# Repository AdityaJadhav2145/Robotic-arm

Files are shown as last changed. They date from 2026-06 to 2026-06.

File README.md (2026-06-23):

# Robotic-arm
"5-DOF Robotic Arm | Arduino UNO + MG995 Servos | SolidWorks CAD &amp; FEA | 3D Printed (PUR)"

 Key Features
 5-DOF Articulated Design - Maximum workspace flexibility for pick-and-place, welding, and assembly tasks

 Cost-Effective - Built with affordable components and 3D printing technology

 3D Printed Structure - PUR links with acrylic components for lightweight yet rigid construction

 CAD Validated - Full SolidWorks assembly with mass properties verification

 FEA Verified - Structural analysis confirming safety factors well within limits

 Arduino Controlled - Easy to program and extend with Arduino ecosystem

 Precision Motion - Servo-driven joints with PWM control

## 👥 Core Team

- **Aditya Jadhav** – *Electronics Design & Integration, System Assembly, Hardware Validation*  
  Responsible for circuit design, component selection (Arduino UNO, PCA9685, MG995 servos), soldering/wiring, and physical assembly of the entire robotic structure. Ensured seamless integration between the electronics stack and mechanical links.

Metric	Result
Payload Capacity	~48 g at full horizontal reach
Governing Constraint	J1 Shoulder & J2 Elbow torque limits
FEA Safety Factor	Min FOS = 260
Maximum Stress	0.176 MPa (Well below yield)
Deformation	Sub-micron range

Degrees of Freedom
Joint 1 - Base Yaw (Servo 1)
Joint 2 - Shoulder Pitch (Servo 2)
Joint 3 - Elbow Pitch (Servo 3)
Joint 4 - Wrist Pitch (Servo 4)
Joint 5 - Wrist Roll (Servo 5)
Joint 6 - Gripper (Servo 6)

Circuit Diagram-

                   ┌─────────────────────────────────────┐
                   │           ARDUINO UNO               │
                   │          ATmega328P                 │
                   │                                     │
     ┌─────────────┤  D3    D5    D6    D9    D10   D11 │
     │             │                                     │
     │             │  SDA (A4)                           │
     │             │  SCL (A5)                           │
     │             │                                     │
     │             │  5V / GND                           │
     │             └──────────────┬──────────────────────┘
     │                            │
     │   ┌────────────────────┐   │
     │   │   PCA9685          │   │
     │   │   16-ch I2C        │   │
     │   │   Servo Driver     │◄──┘
     │   └────────┬───────────┘
     │            │
     │   ┌────────┴────────────┐
     │   │  6V / 5A DC Power   │
     │   │  Supply             │
     │   └────────┬────────────┘
     │            │
     │   ┌────────┴──────────────────────────┐
     │   │  6 × MG995 Servo Motors           │
     │   │  (Base, Shoulder, Elbow,          │
     │   │   Wrist Pitch, Wrist Roll, Gripper)│
     │   └───────────────────────────────────┘
     │
     └── USB / Serial (PC / Arduino IDE)

     🌟 Applications
     
🏭 Industrial Automation
Pick-and-place operations
Repetitive material handling
Conveyor sorting systems

🔬 Research & Education
Teaching kinematics and robotics
Robotics programming courses
FEA validation demonstrations

🏥 Medical Assistance
Rehabilitative therapy support
Surgical assistance (concept)
Pharmaceutical handling

🌐 Remote Operations
Hazardous environment tele-operation
Nuclear facility handling
Deep-sea exploration support

🤖 Collaborative Robotics
Human-robot collaboration studies
Light assembly tasks
Service counter operations

🔧 Rapid Prototyping
Gripper design testing
Sensor integration platform
Control algorithm development

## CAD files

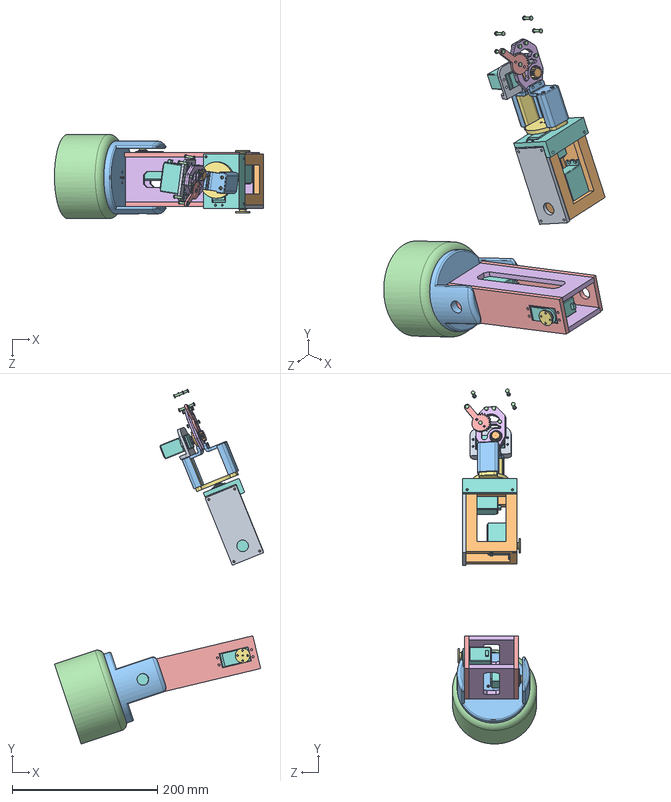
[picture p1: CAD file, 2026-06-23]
tanni bot.SLDASM
287.6 x 488.3 x 116.0 mm
servo.MG995 x 6
[3879] Servo Motor Horn for MG995 MG996 Series Motor SunRobotics_in_fron x 6
link1_1 (2) x 2
LINK1_2 x 2
BASE
link 3
link 3_2
link 3_3
yaw_1
servo holder

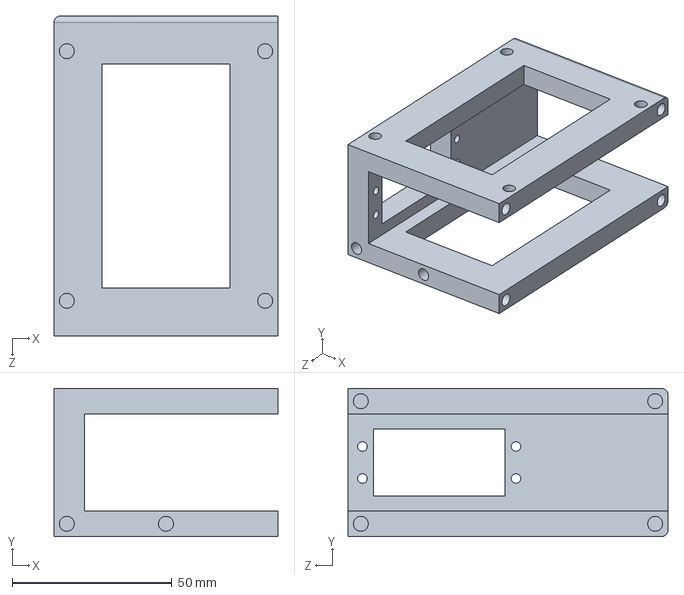
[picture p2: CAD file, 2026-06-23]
link 3.SLDPRT
70.0 x 46.3 x 100.0 mm

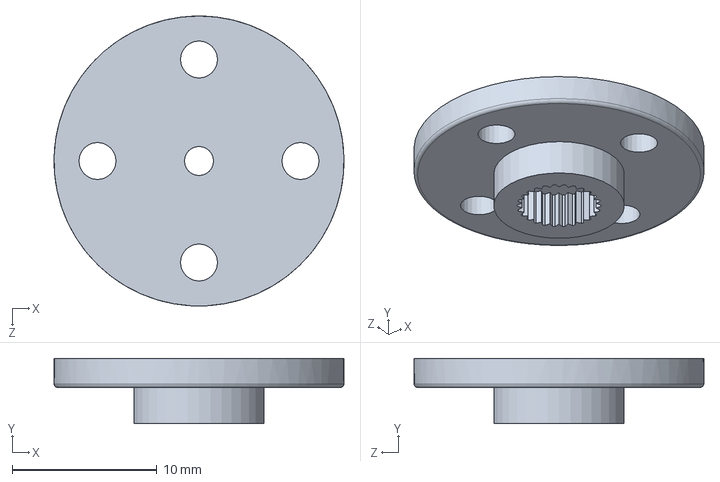
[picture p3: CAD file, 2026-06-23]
[3879] Servo Motor Horn for MG995 MG996 Series Motor SunRobotics_in_fron.SLDPRT
20.0 x 4.50 x 20.0 mm

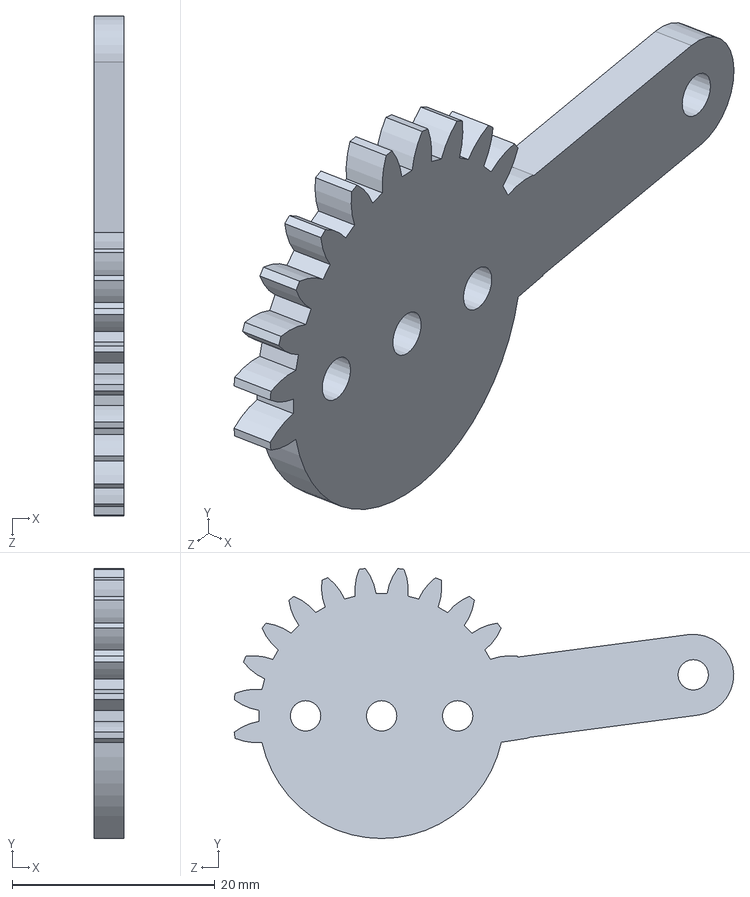
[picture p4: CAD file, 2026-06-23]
part5-5.SLDPRT
3.00 x 26.6 x 49.3 mm

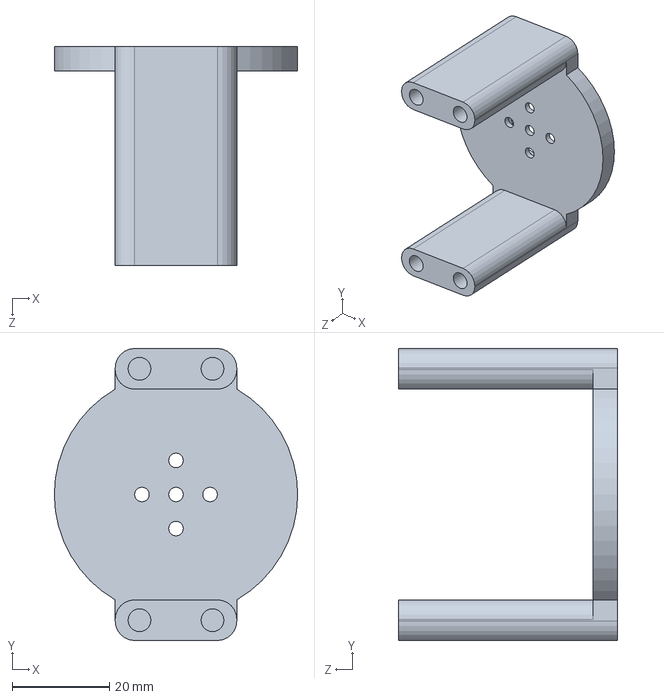
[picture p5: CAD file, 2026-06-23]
yaw_1.SLDPRT
50.0 x 60.0 x 45.0 mm

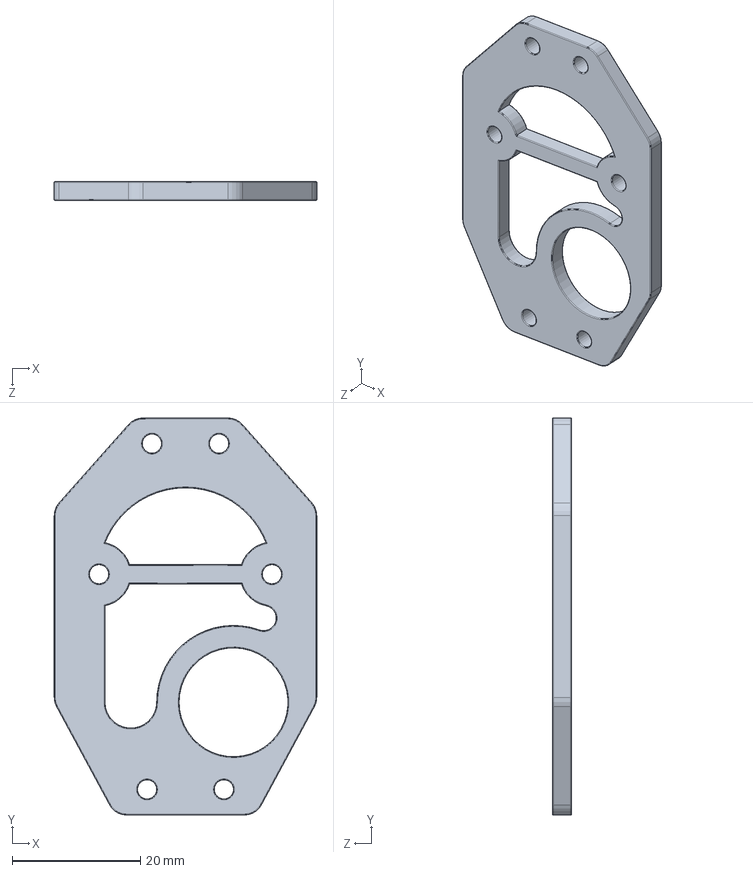
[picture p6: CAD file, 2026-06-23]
Part3-3.SLDPRT
41.0 x 62.0 x 3.00 mm

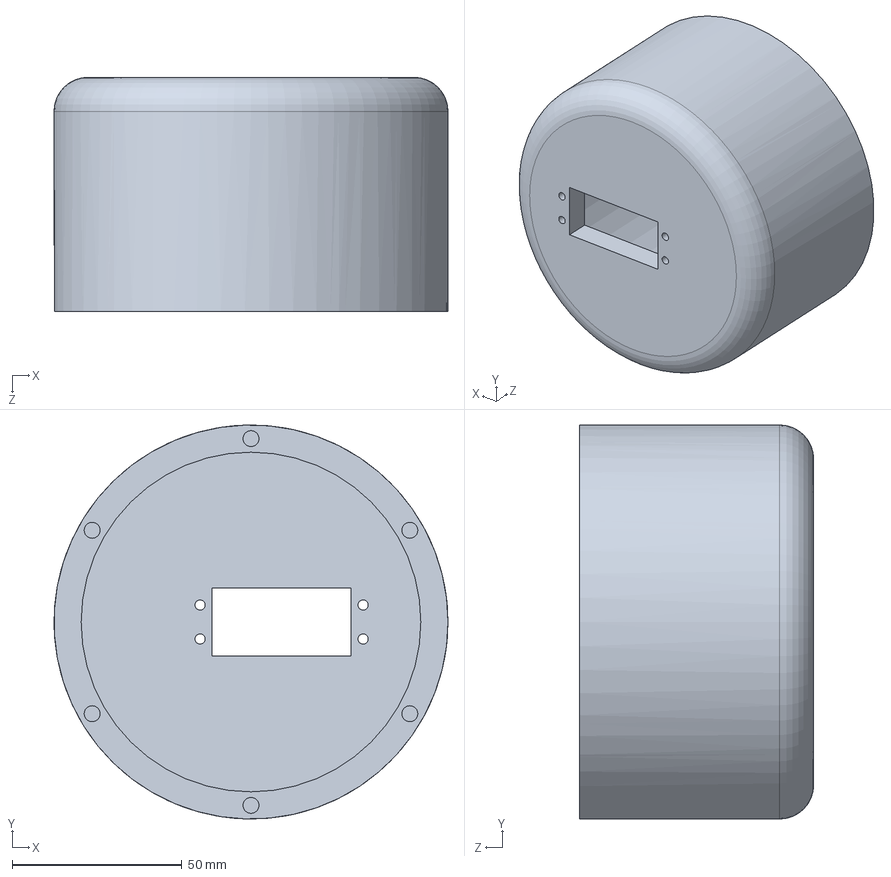
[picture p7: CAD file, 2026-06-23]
BASE.SLDPRT
116.0 x 116.0 x 69.0 mm

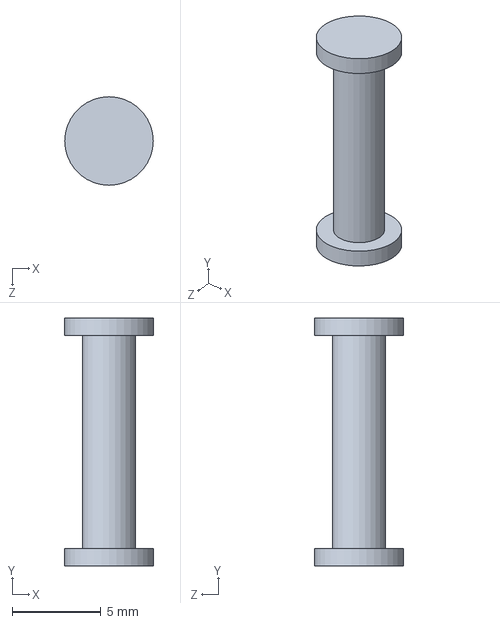
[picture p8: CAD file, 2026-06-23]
Part6-6.SLDPRT
5.00 x 14.0 x 5.00 mm

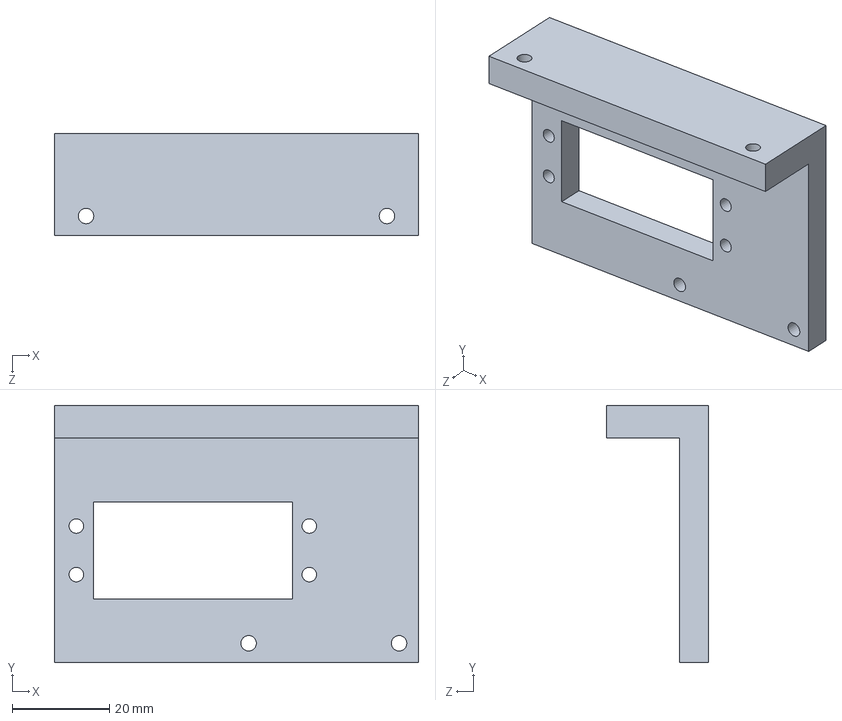
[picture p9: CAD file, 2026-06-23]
link 3_3.SLDPRT
75.0 x 53.0 x 21.0 mm

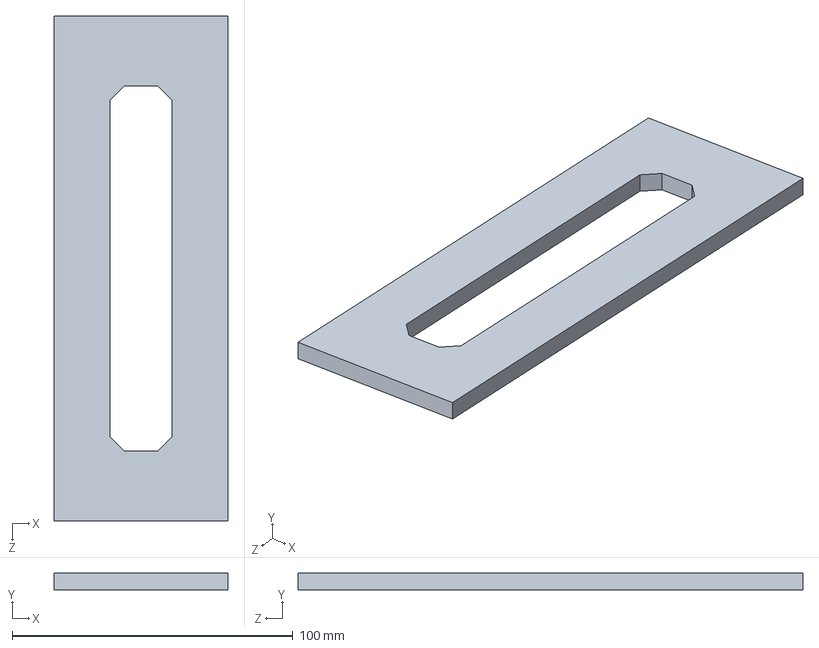
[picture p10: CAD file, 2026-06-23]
link1_1 (2).SLDPRT
62.0 x 6.00 x 180.0 mm

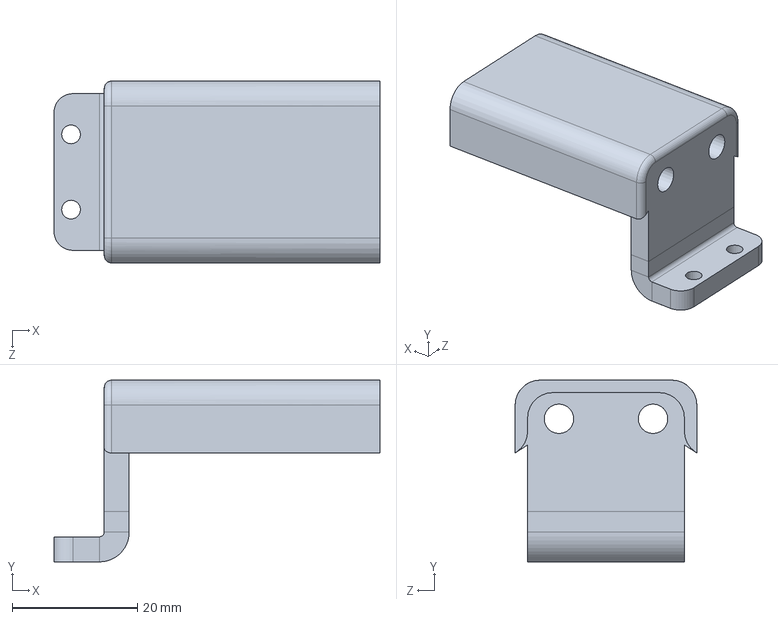
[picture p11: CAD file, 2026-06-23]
Part7-7.SLDPRT
52.0 x 29.0 x 29.0 mm

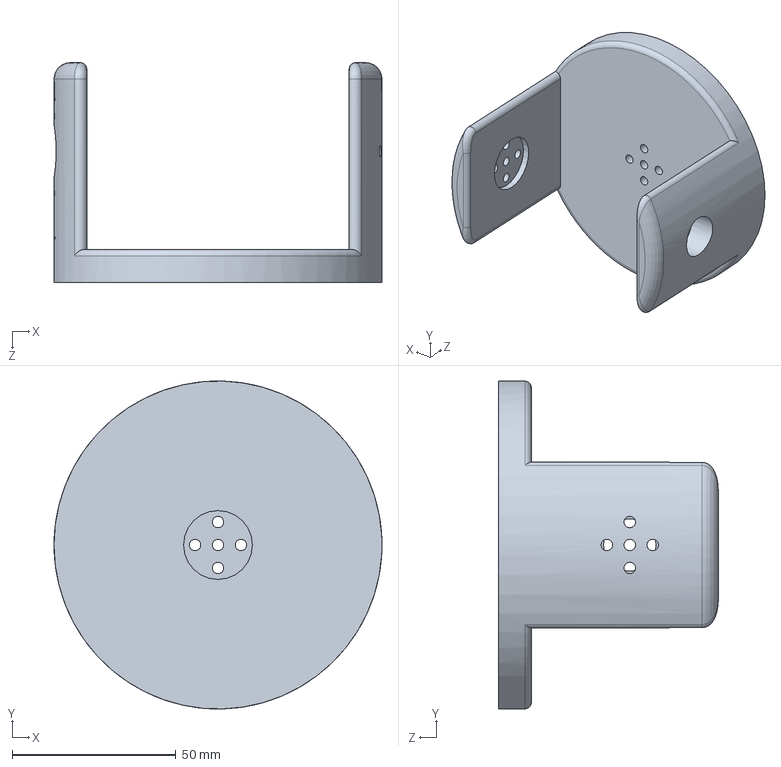
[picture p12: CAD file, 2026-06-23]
Part2.SLDPRT
100.0 x 100.0 x 67.0 mm

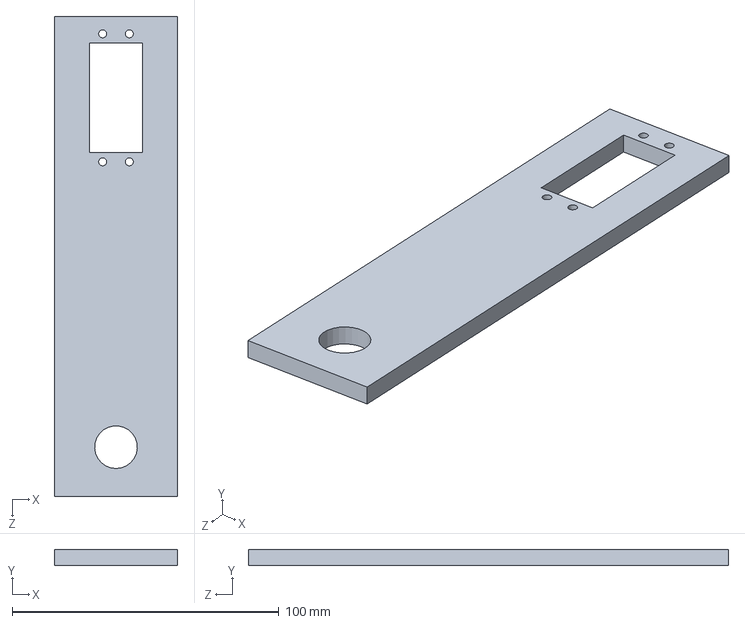
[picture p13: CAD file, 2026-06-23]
LINK1_2.SLDPRT
46.3 x 6.00 x 180.0 mm

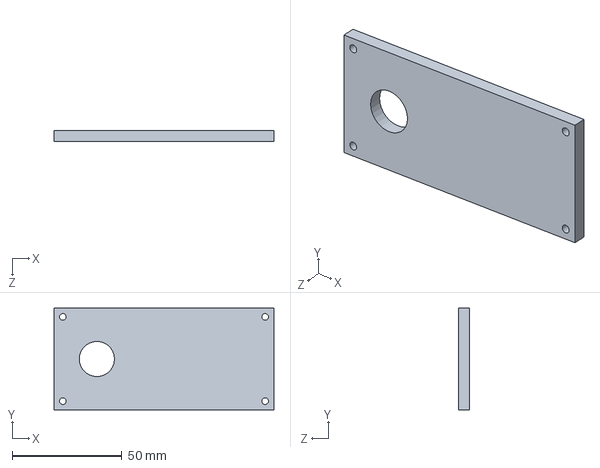
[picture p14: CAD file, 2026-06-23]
link 3_2.SLDPRT
100.0 x 46.3 x 5.00 mm

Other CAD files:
Assem6.SLDASM
servo holder.SLDPRT
part8-8.SLDPRT
servo.MG995.SLDPRT
Part1-1.SLDPRT
Part2-2.SLDPRT
link 2_1 rk.SLDPRT
link 2_2 rk.SLDPRT
part4-4.SLDPRT

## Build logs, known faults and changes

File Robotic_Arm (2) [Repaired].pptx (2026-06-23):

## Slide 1

Robotic Arm

5-DOF Articulated Robotic Arm

Department of Mechanical Engineering | 2025–26

1044 g

Total Mass

5 DOF

Degrees of Freedom

MG995

Servo Motors × 6

PUR

Print Material

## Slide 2

OVERVIEW

Presentation Outline

Introduction

Background & motivation for robotic arms

01

FEA Analysis

Structural simulation results

06

Problem Statement

Challenges addressed by Tanni Bot

02

Torque & Payload

Joint torque calculations

07

Objectives

Goals and success criteria

03

Circuit Diagram

Arduino UNO control system

08

Components Used

Hardware, electronics & software

04

Output & Results

Simulation & physical results

09

Mechanical Design

SolidWorks CAD & 3D-printed assembly

05

Applications

Real-world use cases

10

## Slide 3

01 — INTRODUCTION

Introduction to Robotic Arms

What is a Robotic Arm?

A mechanical manipulator mimicking human arm motion, capable of precise positioning in 3D space through multiple joints.

Why Articulated?

Articulated arms with revolute joints offer maximum flexibility and workspace coverage, essential for pick-and-place, welding, and assembly.

5 Degrees of Freedom

Each DOF adds an independent axis of motion — enabling complex trajectories and orientations unreachable by simpler designs.

Project Context

Tanni Bot is a 3D-printed, servo-driven robotic arm designed and simulated entirely in SolidWorks, then validated through FEA.

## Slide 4

02 — PROBLEM STATEMENT

Problem Statement

"How can we design and fabricate a low-cost, multi-DOF articulated robotic arm using 3D printing and off-the-shelf servo motors, validated through FEA and kinematic analysis?"

💰 High Cost of Commercial Arms

Industrial arms cost ₹5–50 lakhs. Existing low-cost options lack rigidity and precision for education/research use.

⚙️ Structural Integrity Under Load

Lightweight 3D-printed materials must withstand servo torques and payload without deformation or failure.

🔗 Complex Multi-Joint Coordination

Coordinating 5 DOF with limited servo torque requires careful kinematic planning and torque-chain analysis.

📐 Geometric & Mass Accuracy

CAD-to-print accuracy must be validated; mass and inertia properties need verification for dynamic performance.

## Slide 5

03 — OBJECTIVES

Project Objectives

01

Design a 5-DOF articulated robotic arm in SolidWorks with full assembly, mate constraints, and mass properties verification.

04

Perform FEA (Finite Element Analysis) on critical links using SolidWorks Simulation to verify stress within limits.

02

Select appropriate MG995 servo motors based on torque requirements computed via static load analysis.

05

Develop Arduino UNO-based control system for coordinated multi-joint actuation via servo PWM signals.

03

3D-print structural links in PUR (Polyurethane) material and validate dimensional accuracy against CAD model.

06

Analyse payload capacity, joint torques, and safety factors across all operating configurations.

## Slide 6

04 — COMPONENTS USED

Components Used

Microcontroller

Arduino UNO (ATmega328P)
6 PWM output pins
5V / 3.3V regulated supply

Actuators

6× MG995 Metal Gear Servo
Stall torque: 13 kg·cm @ 6V
Operating voltage: 4.8–7.2V

Structure

3D-Printed PUR links
Acrylic (LINK 1)
Stainless steel fasteners

Electronics

PCA9685 16-ch Servo Driver
6V / 5A DC Power Supply
Jumper wires & breadboard

Software

SolidWorks 2024/2025
SolidWorks Simulation (FEA)
Arduino IDE

Sensors / I/O

Potentiometer knobs (manual)
USB serial for Arduino
Servo feedback (optional)

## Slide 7

05 — MECHANICAL DESIGN

SolidWorks CAD — Full Assembly

Total Mass:

Volume:

Surface Area:

CoM (X,Y,Z):

DOF:

1044.39 g

1,044,311 mm³

398,771 mm²

525, 802, 1354 mm

5 (6 servos)

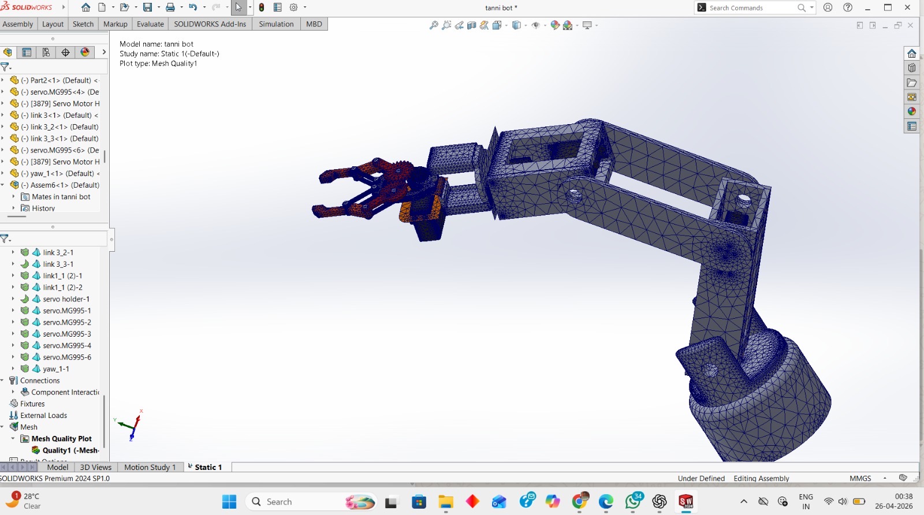
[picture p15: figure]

FEM Mesh Quality View (SolidWorks Simulation)

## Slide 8

05 — MECHANICAL DESIGN

Assembly Segment Mass Breakdown

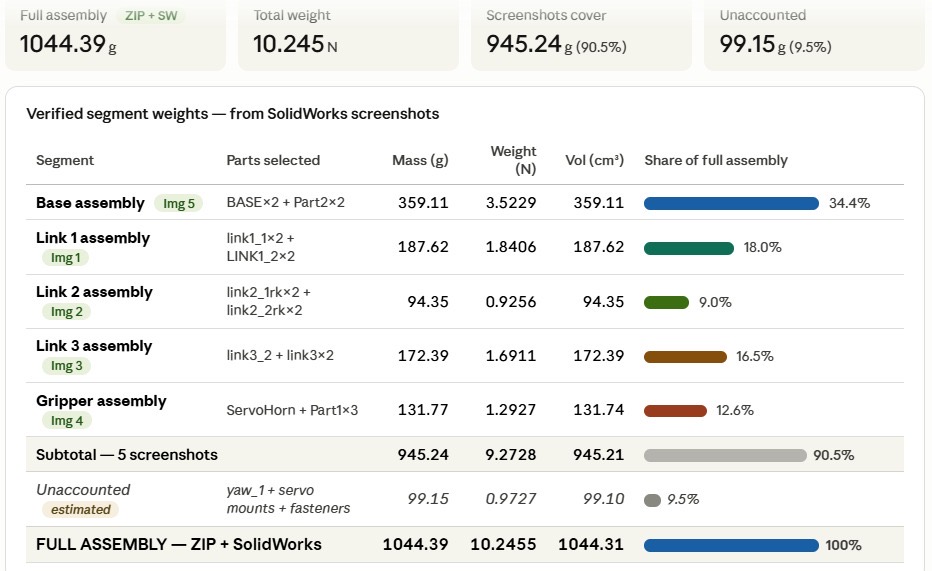
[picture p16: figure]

Total Assembly: 1044.39 g | 10.245 N | 90.5% of mass accounted by photographed segments

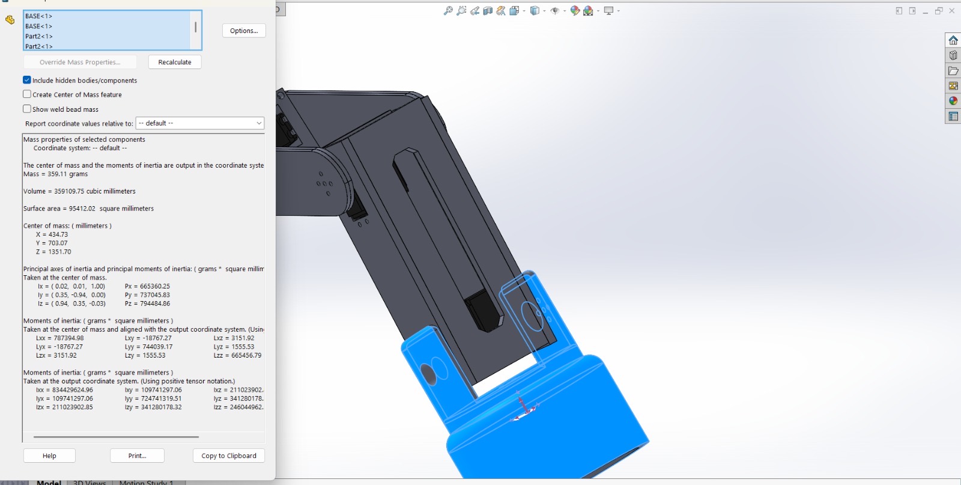
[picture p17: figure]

Base Assembly
359.11 g

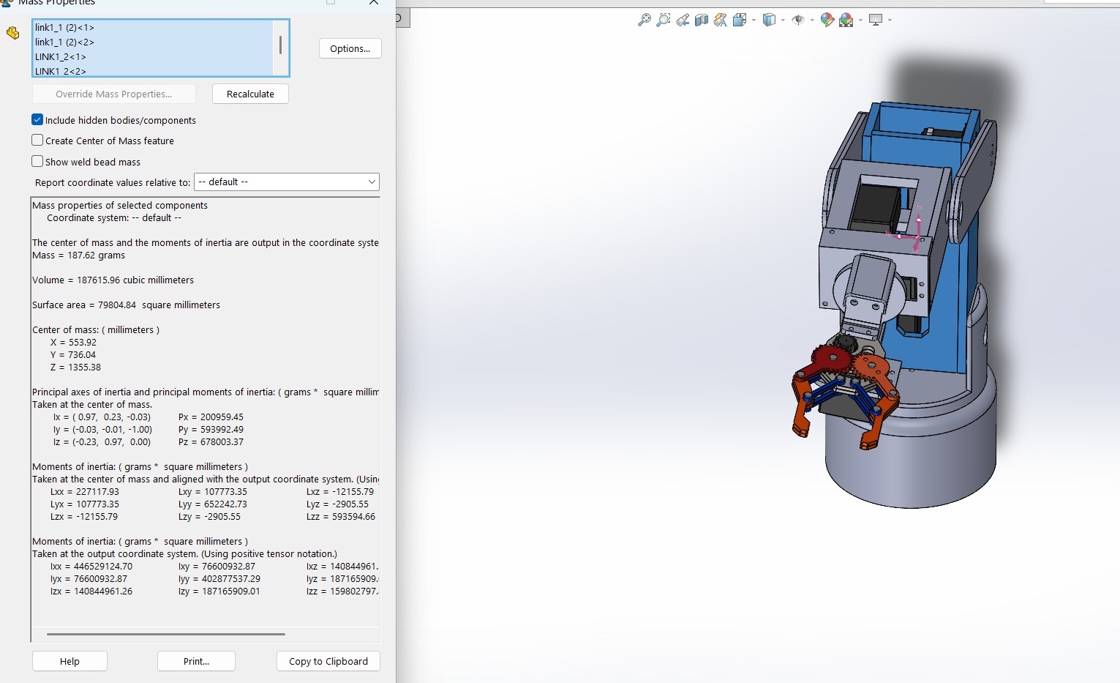
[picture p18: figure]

Link 1
187.62 g

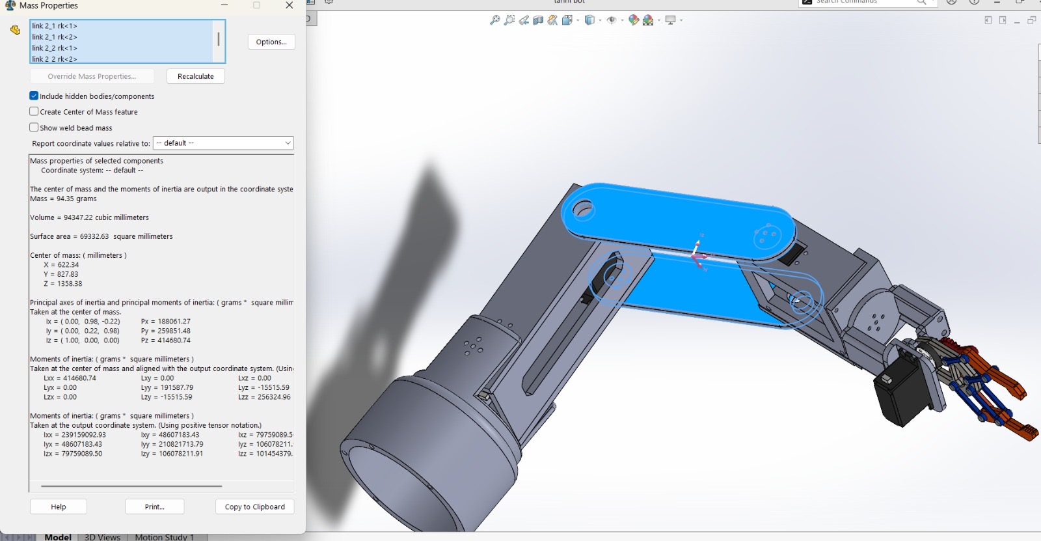
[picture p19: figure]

Link 2
94.35 g

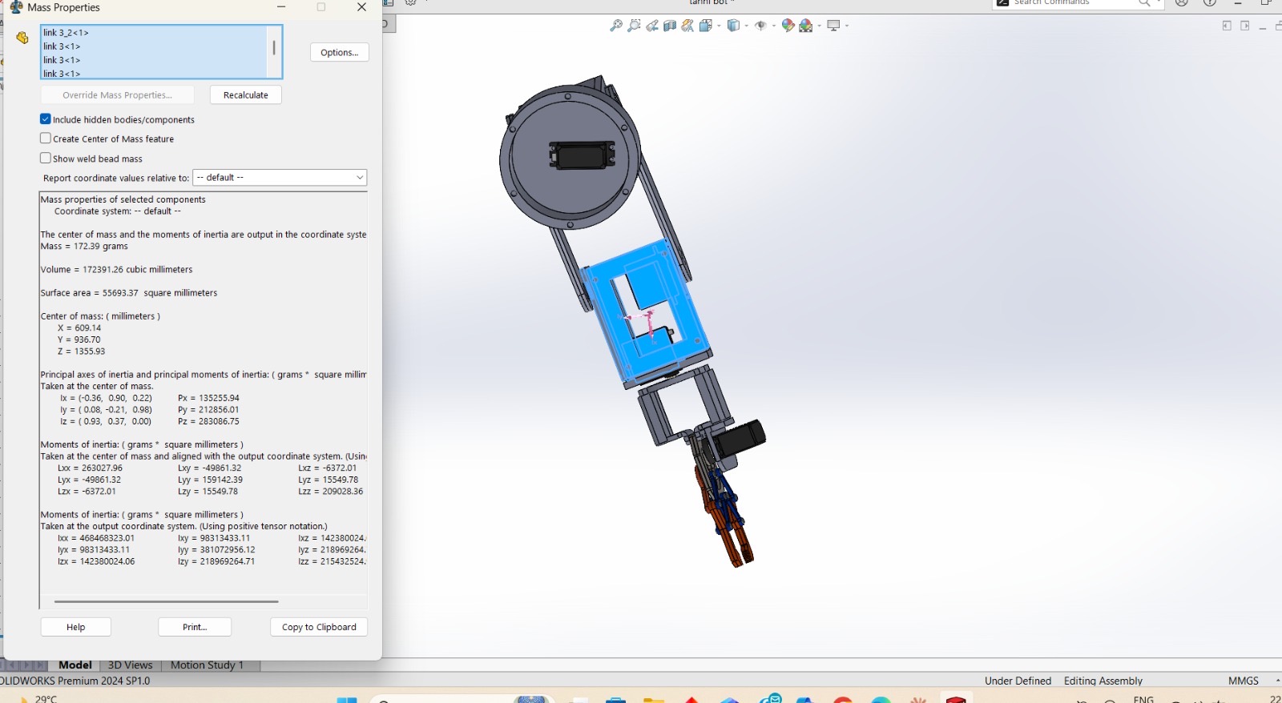
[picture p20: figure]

Link 3
172.39 g

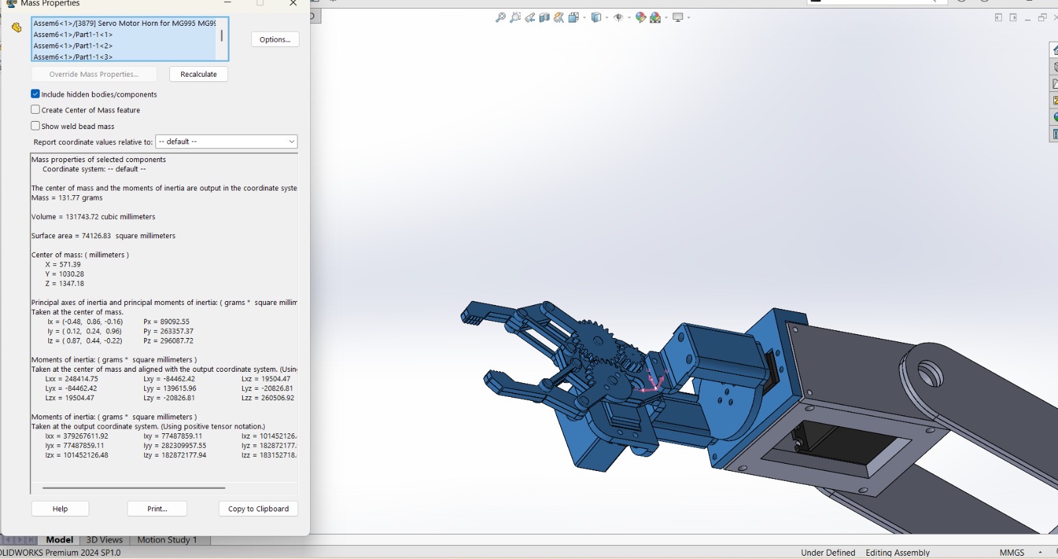
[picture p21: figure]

Gripper
131.77 g

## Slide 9

06 — FEA STRUCTURAL ANALYSIS

FEA — Link 3 (PUR Material)

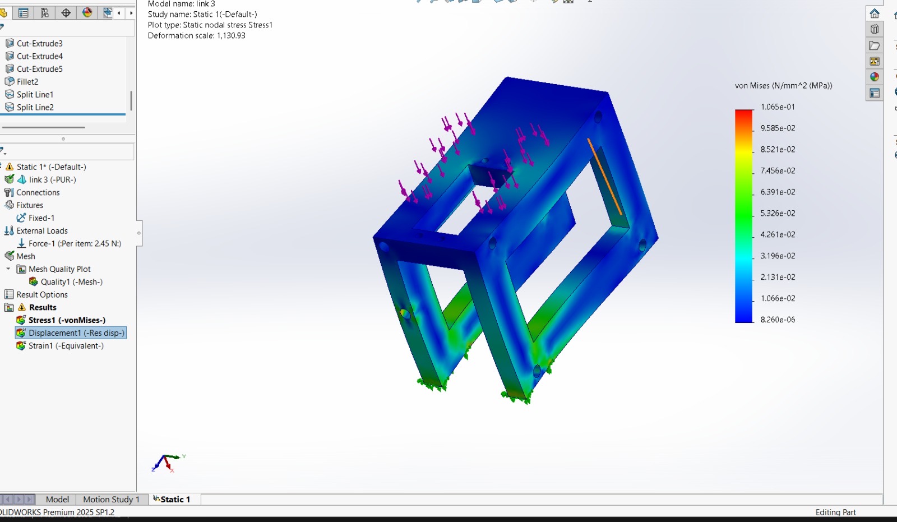
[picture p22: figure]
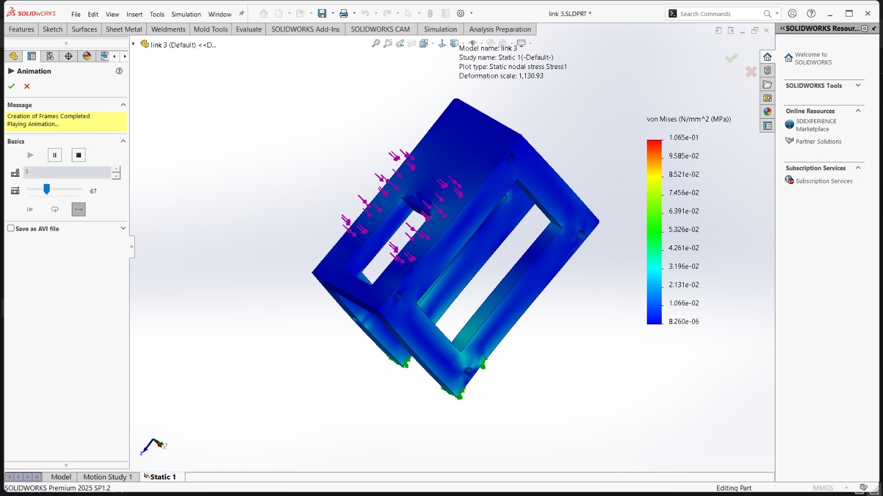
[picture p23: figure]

Material: PUR (Polyurethane)

Load Applied: 2.45 N per item

Max von Mises: 0.1065 MPa

Min von Mises: 8.26×10⁻⁶ MPa

Result: Well within yield limit

Deformation Scale: 1,130.93 — Stress distribution is predominantly low (blue), confirming design safety

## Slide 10

06 — FEA STRUCTURAL ANALYSIS

FEA — Link 1 (Acrylic Material)

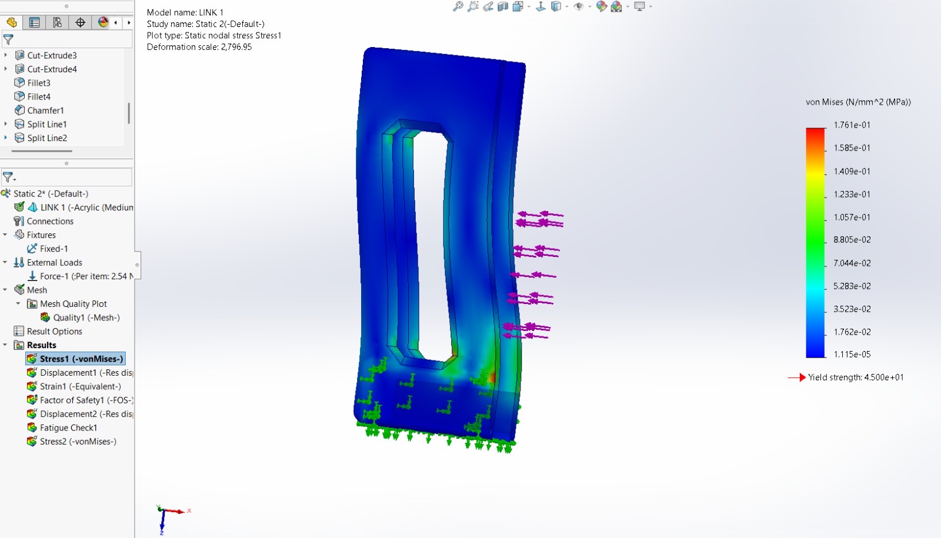
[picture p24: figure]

Von Mises Stress
(Static nodal)

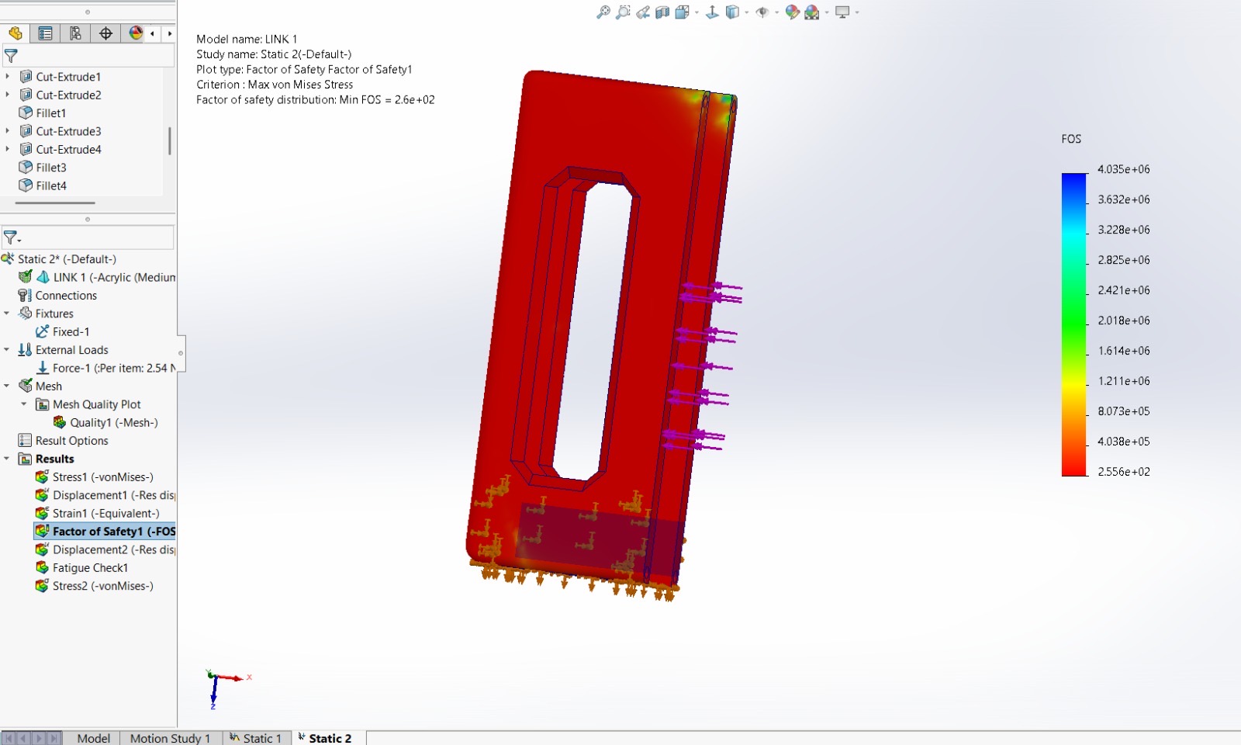
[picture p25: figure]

Factor of Safety
Min FOS = 260

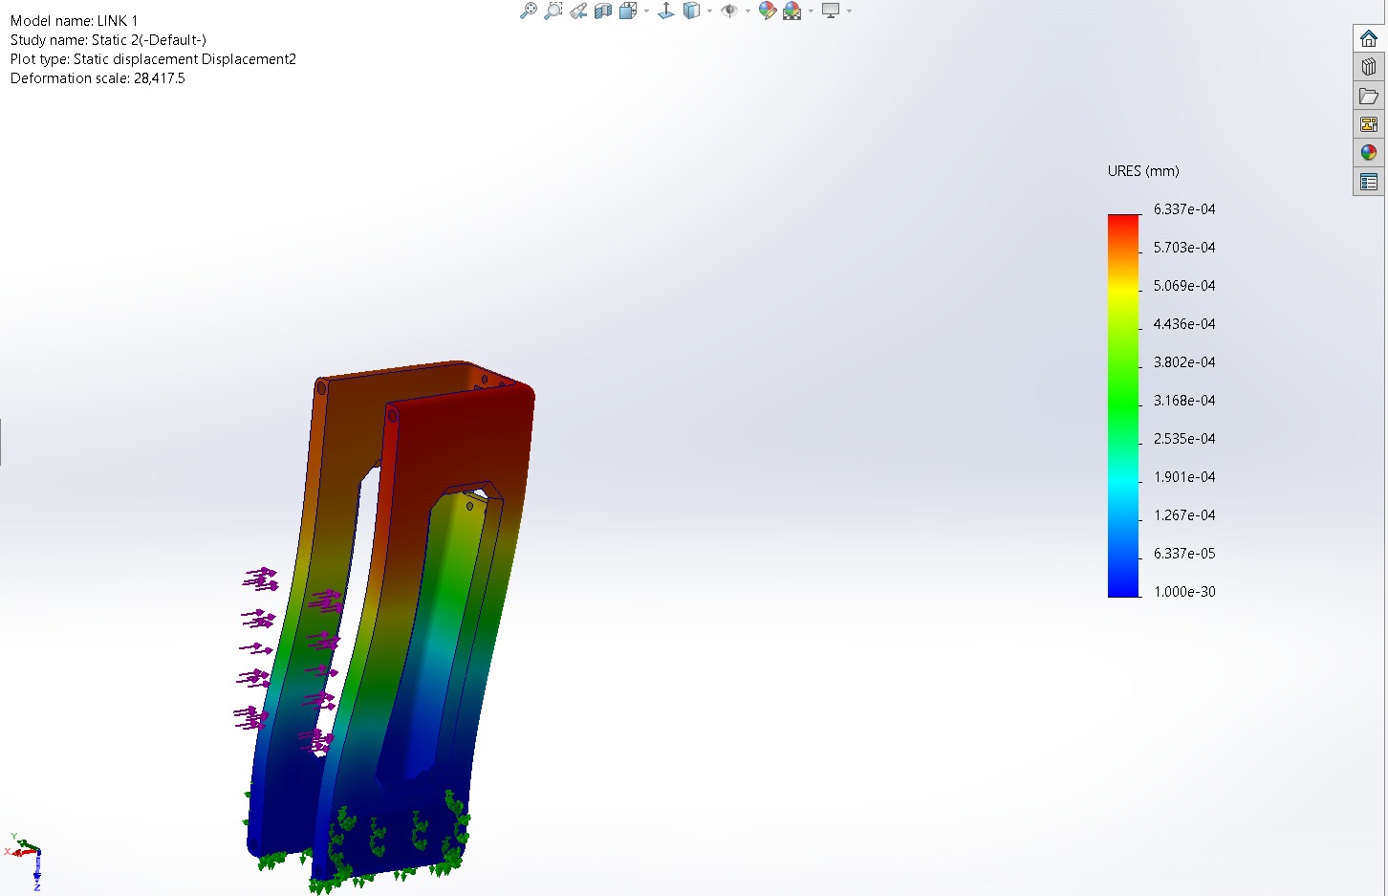
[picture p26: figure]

Displacement
URES (mm)

Load: 2.54 N | Material: Acrylic (Medium Impact) | Yield Strength: 45 MPa | Max Stress: 0.176 MPa | Min FOS: 260 | Status: SAFE ✓

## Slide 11

06 — FEA STRUCTURAL ANALYSIS

FEA — Link 3_3 Shell Analysis

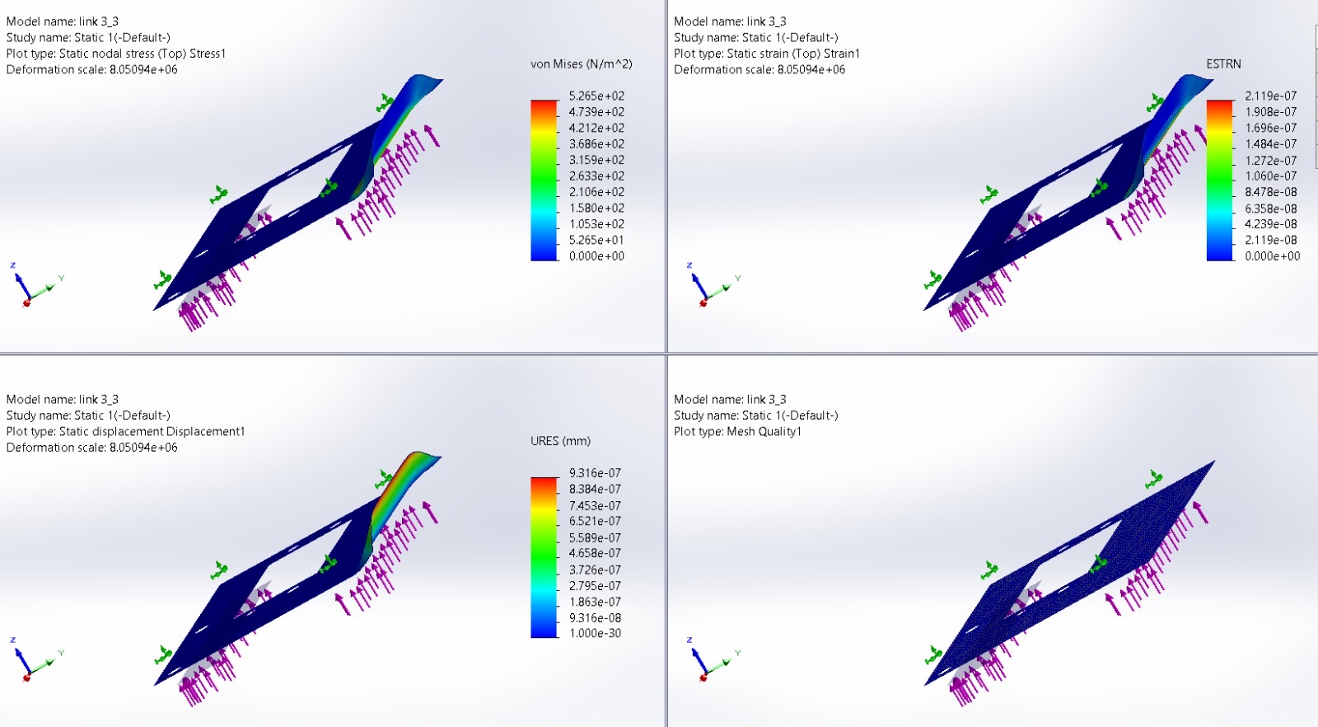
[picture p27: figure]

4-panel result view: Von Mises Stress | Equivalent Strain | Resultant Displacement | Mesh Quality — All results indicate negligible deformation (sub-micron range)

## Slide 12

07 — TORQUE & PAYLOAD ANALYSIS

Joint Torque & Payload Capacity

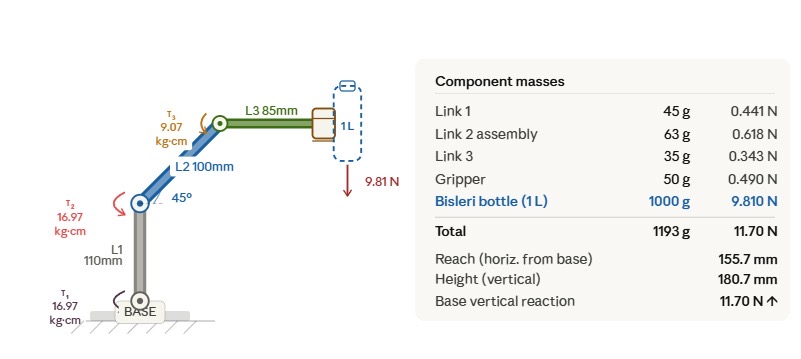
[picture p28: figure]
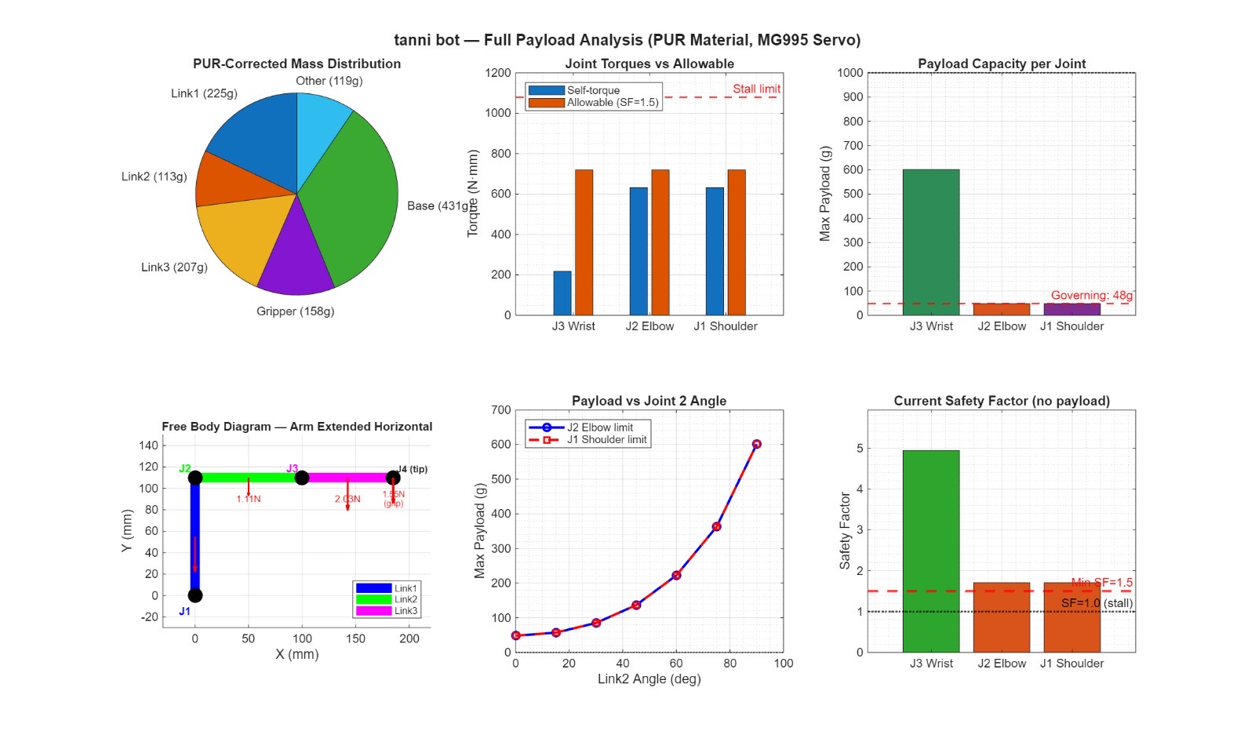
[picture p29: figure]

Joint | Self-Torque | Allowable (SF=1.5) | Payload
J1 Shoulder | 620 N·mm | 700 N·mm | 48 g
J2 Elbow | 620 N·mm | 700 N·mm | 55 g
J3 Wrist | 207 N·mm | 700 N·mm | 600 g

⚠ Governing constraint: J1 Shoulder & J2 Elbow limit payload to ~48 g at full horizontal reach

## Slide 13

08 — CIRCUIT DIAGRAM

Arduino UNO Control System

6V / 5A
DC Power
Supply

ARDUINO UNO
ATmega328P

PCA9685
16-ch I2C
Servo Driver

5V / GND

D3

I2C (SDA/SCL)

D5

D6

MG995
Servos
×6

D9

D10

Servo 1
Base Yaw

D11

Servo 4
Wrist Pitch

Servo 2
Shoulder

PC / Serial

USB / Serial

Servo 5
Wrist Roll

Servo 3
Elbow

Servo 6
Gripper

Signal flow: PC → Arduino UNO → PCA9685 (I2C) → MG995 Servos (PWM) | Power: 6V @ 5A → Servos & Driver

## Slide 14

09 — OUTPUT & RESULTS

Simulation & Physical Results

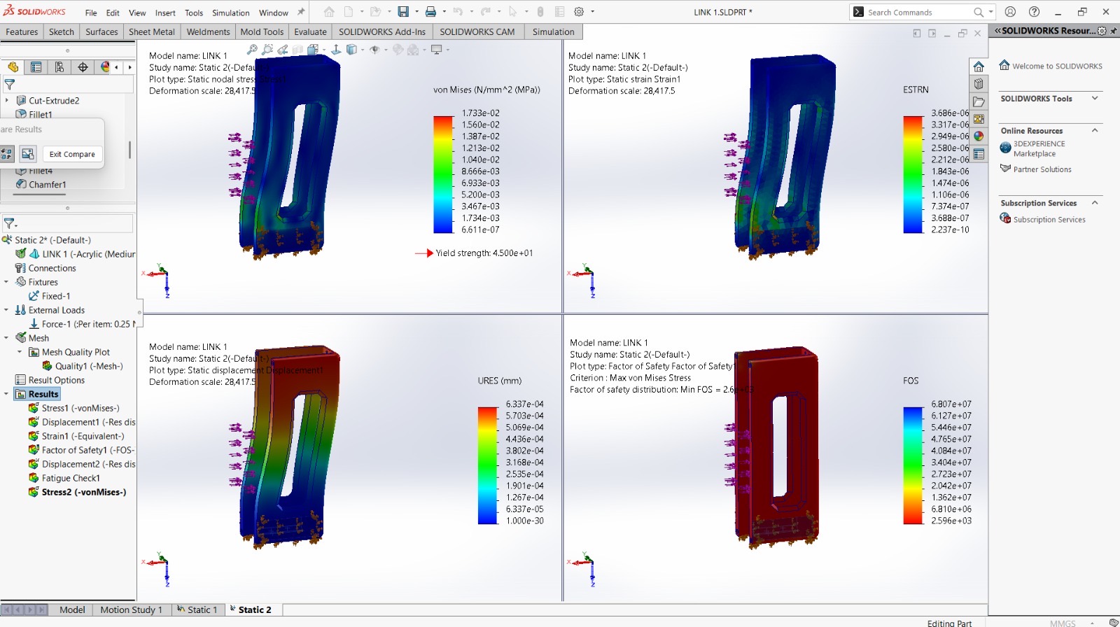
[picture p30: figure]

Max Stress (Link 1) | 0.176 MPa | Yield: 45 MPa — SAFE
Min FOS (Link 1) | 260× | Far above SF=1.5 target
Max Stress (Link 3) | 0.107 MPa | PUR well within limits
Link 3_3 Displacement | <1 μm | Negligible deformation
Total Assembly Mass | 1044.39 g | SolidWorks verified
Governing Payload | ~48 g | Limited by J1/J2 torque

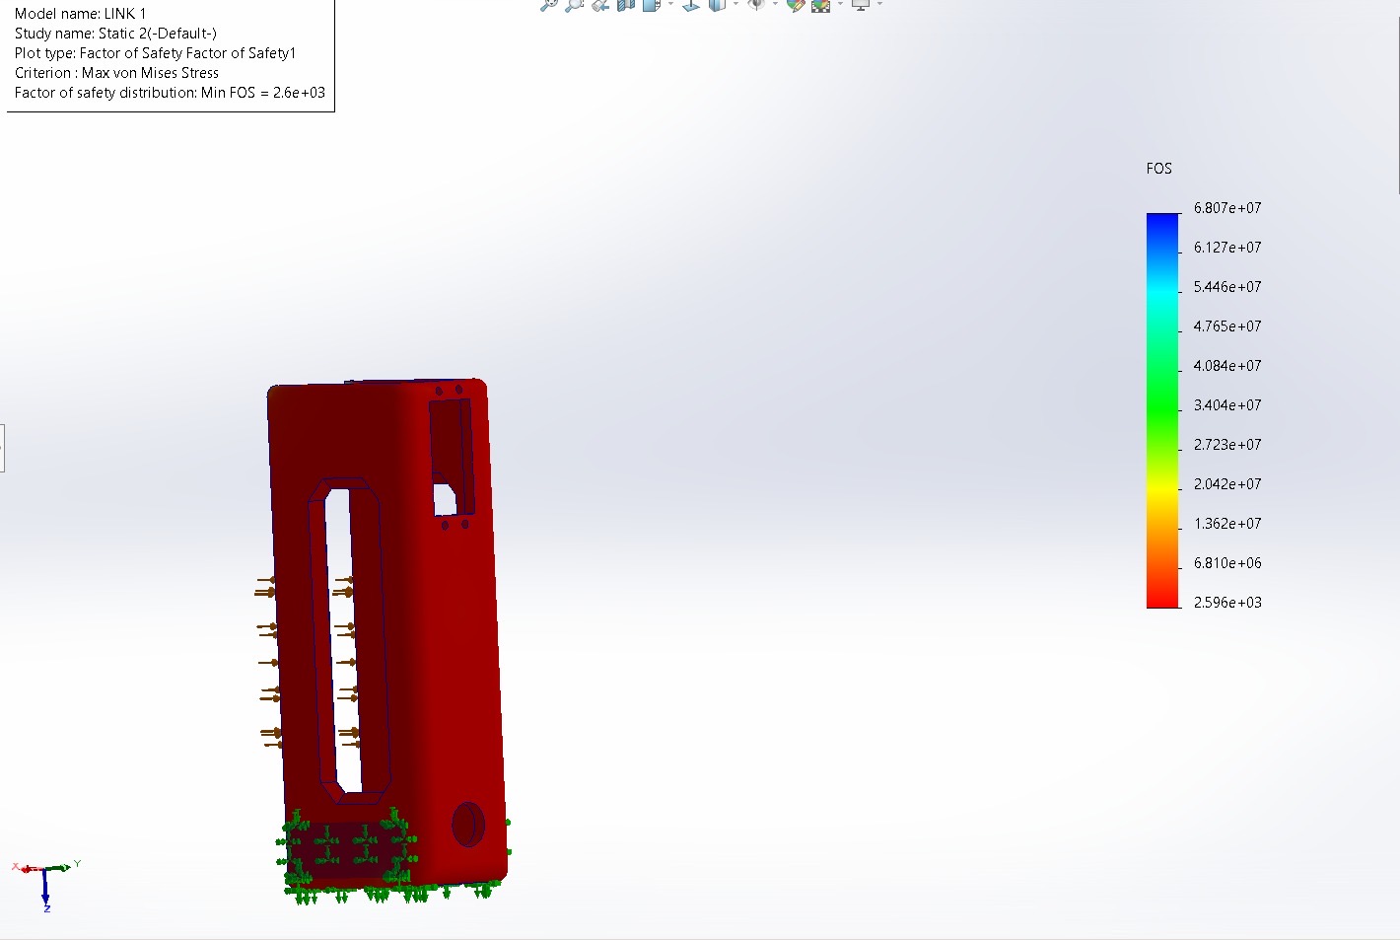
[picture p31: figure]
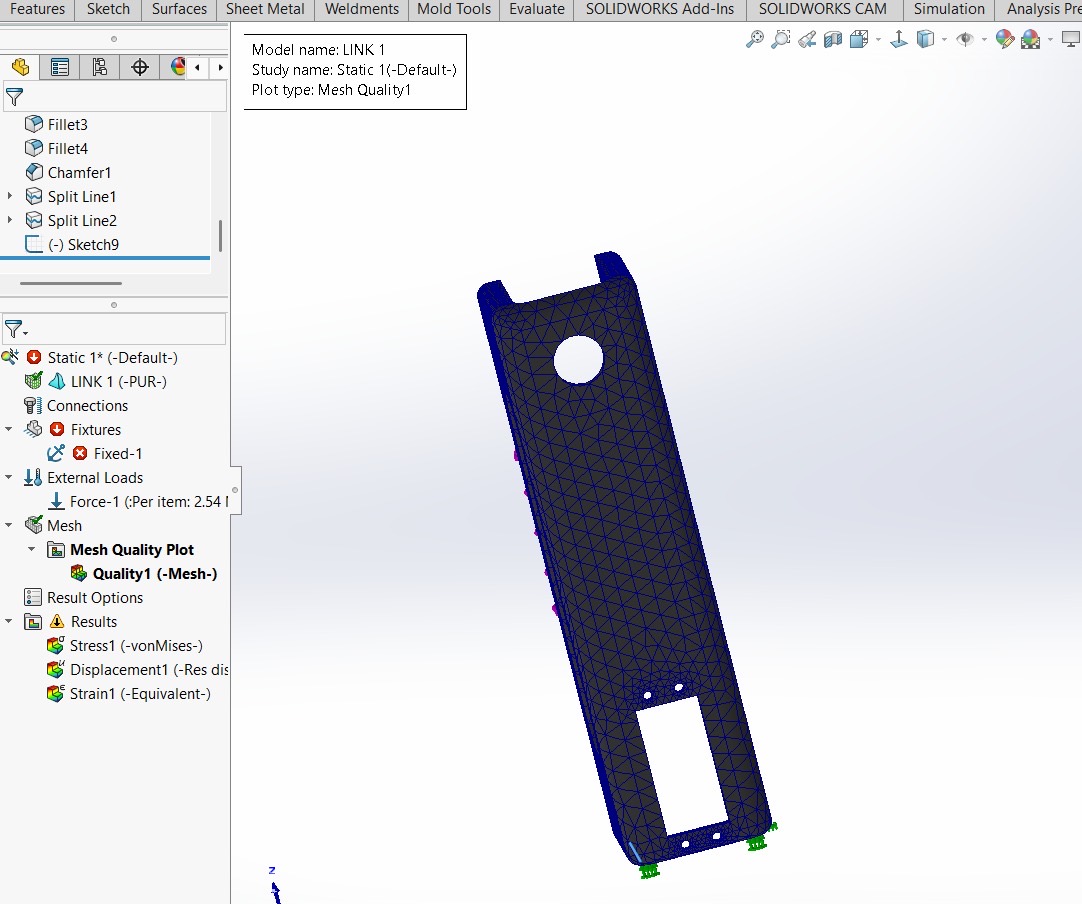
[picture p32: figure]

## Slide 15

10 — APPLICATIONS

Applications & Future Scope

🏭

Industrial Automation

Pick-and-place in assembly lines, repetitive material handling, conveyor sorting.

🔬

Research & Education

Teaching kinematics, robotics programming, and FEA validation in academic labs.

🏥

Medical Assistance

Rehabilitative therapy arms, surgical assistance, pharmaceutical pick-and-place.

🌐

Remote Operations

Tele-operation in hazardous environments (nuclear, chemical, deep sea).

🤖

Collaborative Robotics

Human-robot collaboration on light assembly tasks and service counters.

🔧

Rapid Prototyping

Low-cost platform for testing gripper designs, sensors, and control algorithms.

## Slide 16

Thank You

TANNI BOT — 5-DOF Articulated Robotic Arm

✓ 5 DOF | 6× MG995 Servo Motors

✓ Total Mass: 1044.39 g | Verified by SolidWorks

✓ FEA: Min FOS = 260 | Stress well within limits

✓ Arduino UNO + PCA9685 control system

✓ 3D printed PUR & Acrylic structural links

Department of Mechanical Engineering | 2025–26

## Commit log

2026-06-23 Rename tanni bot (2).zip to Robotic arm solidworks (2).zip
2026-06-23 Expand README with technical details and applications
    Added sections on Degrees of Freedom, Circuit Diagram, and Applications.
